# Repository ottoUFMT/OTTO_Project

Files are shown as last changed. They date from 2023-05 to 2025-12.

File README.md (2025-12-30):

# 🤖 Robô Otto - Repositório Oficial

<div align="center">






**Robô educacional interativo com reconhecimento RFID, controle remoto IR, teclado matricial e matriz de LEDs**

[📖 Documentação](#-documentação) • [⚙️ Instalação](#️-instalação) • [🎯 Funcionalidades](#-funcionalidades) • [🚀 Roadmap](#-próximas-funcionalidades)

</div>

---

## 📋 Índice

- [Sobre o Projeto](#-sobre-o-projeto)
- [Características Principais](#-características-principais)
- [Documentação](#-documentação)
- [Pré-requisitos](#-pré-requisitos)
- [Instalação](#️-instalação)
- [Componentes de Hardware](#-componentes-de-hardware)
- [Bibliotecas e Versões](#-bibliotecas-e-versões)
- [Funcionalidades Atuais](#-funcionalidades-atuais)
- [Esquema de Conexões](#-esquema-de-conexões)
- [Como Usar](#-como-usar)
- [Próximas Funcionalidades](#-próximas-funcionalidades)
- [Modelagem 3D](#-modelagem-3d)
- [Troubleshooting](#-troubleshooting)
- [Contribuindo](#-contribuindo)
- [Autores](#-autores)
- [Referências](#-referências)
- [Licença](#-licença)

---

## 🎯 Sobre o Projeto

O **Otto** é um robô educacional open-source desenvolvido para ensinar programação, eletrônica e robótica de forma interativa e divertida. Este repositório contém a versão atual do código, completamente refatorada e documentada, além dos arquivos de modelagem 3D para impressão.

### ✨ Características Principais

- 🎵 **Sistema de Áudio**: Reprodução de músicas e efeitos sonoros via DFPlayer Mini
- 😊 **Expressões Faciais**: Matriz LED 8x8 com 10+ emoções diferentes
- 🎮 **Controle Remoto**: Interface via controle infravermelho
- 💳 **Leitor RFID**: Reconhecimento de cartões para comandos personalizados
- ⌨️ **Teclado Matricial**: 10 teclas para interação direta
- 🕺 **Movimentos**: 4 servos para braços e pernas com coreografias
- 🧠 **Sistema Inteligente**: Respostas emocionais e comportamentos interativos

---

## 📖 Documentação

### 📂 Estrutura do Projeto

```
OTTO_v1_v2/
├──Hardware
│  ├── Bateria.png                #Esquematico da Bateria 
│  ├── Componentes.png            #Esquematico dos Componentes 
│  └── Hardware_2025.pdf          #Esquematicos com melhor resolução 
├──Modelagem_3d
│   ├── amarelo                   #Arquivos para impressão 3D
│   ├── azul                      #Arquivos para impressão 3D
│   └── preto                     #Arquivos para impressão 3D
├──Software
│  └── Programacao_2025.ino       #Código
├──old_versions                   #Arquivos pré 2025
└── README.md                     #Este arquivo
```

### 🔧 Linguagem e Plataforma

- **Linguagem**: C++ (Arduino Framework)
- **Plataforma**: Arduino Mega 2560
- **IDE**: Arduino IDE 1.8.19 ou superior
- **Compilador**: AVR-GCC

---

## 💻 Pré-requisitos

Antes de começar, certifique-se de ter:

### Software

- ✅ **[Visual Studio](https://visualstudio.microsoft.com/pt-br/#vs-section)** - Redistributable C++ (necessário para Arduino IDE)
- ✅ **[Java JRE](https://www.java.com/pt-BR/download/ie_manual.jsp?locale=pt_BR)** 8 ou superior - Runtime para Arduino IDE
- ✅ **[Arduino IDE](https://www.arduino.cc/en/software)** 1.8.19 - Ambiente de desenvolvimento

### Hardware Necessário

| Componente | Quantidade | Especificação |
|---|---|---|
| Arduino Mega 2560 pro mini | 1x | Microcontrolador principal |
| Servo Motor SG90 | 4x | Movimentação de braços e pernas |
| DFPlayer Mini | 1x | Módulo de áudio MP3 |
| Alto-falante | 1x | 3W, 8Ω |
| MFRC522 | 1x | Leitor RFID 13.56MHz |
| Matriz LED 8x8 | 1x | MAX7219 |
| Receptor IR | 1x | VS1838B ou similar |
| Teclado Matricial | 1x | 2x5 (10 teclas) |
| Regulador de Tensão | 1x | LM2596 ou similar (5V, 3A) |
| Bateria | 1x | 7.4V LiPo 2S ou 6x AA |
| Resistores | Diversos | 1kΩ, 10kΩ |

---

## ⚙️ Instalação

### 1️⃣ Preparar o Ambiente

```bash
# 1. Instale Visual Studio Redistributable C++
# Baixe em: https://visualstudio.microsoft.com/pt-br/downloads/

# 2. Instale Java JRE
# Baixe em: https://www.java.com/pt-BR/download/

# 3. Instale Arduino IDE 1.8.19
# Baixe em: https://www.arduino.cc/en/software/OldSoftwareReleases
```

### 2️⃣ Instalar Bibliotecas

Abra o Arduino IDE e instale as bibliotecas via **Sketch → Include Library → Manage Libraries**:

| Biblioteca | Versão | Instalação |
|---|---|---|
| **DFRobotDFPlayerMini** | 1.0.5 | Gerenciador de Bibliotecas |
| **LedControl** | 1.0.6 | Gerenciador de Bibliotecas |
| **MFRC522** | 1.4.10 | Gerenciador de Bibliotecas |
| **IRremote** | 4.0.0+ | [GitHub](https://github.com/Arduino-IRremote/Arduino-IRremote) |
| **Keypad** | 3.1.1 | Gerenciador de Bibliotecas |

**Bibliotecas Nativas** (já incluídas no Arduino):
- `Servo.h`
- `SPI.h`
- `SoftwareSerial.h`
- `avr/wdt.h`

### 3️⃣ Preparar Cartão SD

1. Formate o cartão SD em **FAT32**
2. Crie uma pasta chamada `mp3` na raiz
3. Adicione arquivos de áudio nomeados como:
   - `0001.mp3` - Som de ligar
   - `0002.mp3` - Som de desligar
   - `0084.mp3` - Emoção: Triste
   - `0085.mp3` - Emoção: Feliz
   - (Continue conforme a tabela de áudios)

### 4️⃣ Upload do Código

```bash
# 1. Conecte o Arduino Mega via USB
# 2. Selecione a placa: Tools → Board → Arduino Mega 2560
# 3. Selecione a porta: Tools → Port → COMx (Windows) ou /dev/ttyUSBx (Linux)
# 4. Clique em Upload (→)
```

---

## 🔌 Componentes de Hardware

### Pinagem Detalhada

#### **Servos Motores**
```cpp
Pino 2  → Perna Esquerda (Left Foot)
Pino 3  → Perna Direita (Right Foot)
Pino 6  → Braço Esquerdo (Left Arm)
Pino 7  → Braço Direito (Right Arm)
```

#### **DFPlayer Mini (Áudio)**
```cpp
Pino 11 → RX (DFPlayer)
Pino 10 → TX (DFPlayer)
        → VCC → 5V (regulado)
        → GND → GND
        → SPK+ → Alto-falante +
        → SPK- → Alto-falante -
```

#### **MFRC522 (RFID)**
```cpp
Pino 5  → RST
Pino 53 → SDA/SS
Pino 51 → MOSI
Pino 50 → MISO
Pino 52 → SCK
        → 3.3V → 3.3V
        → GND → GND
```

#### **Matriz LED 8x8 (MAX7219)**
```cpp
Pino 22 → DIN (Data In)
Pino 24 → CLK (Clock)
Pino 26 → CS (Chip Select)
        → VCC → 5V
        → GND → GND
```

#### **Receptor IR**
```cpp
Pino 13 → Signal
        → VCC → 5V
        → GND → GND
```

#### **Teclado Matricial 2x5**
```cpp
Linhas:  Pino 40, 38
Colunas: Pino 42, 44, 46, 48, 47
```

---

## 📚 Bibliotecas e Versões

| Biblioteca | Versão | Descrição | Download |
|---|---|---|---|
| **Arduino IDE** | 1.8.19 / 1.8.57.0 | Ambiente de desenvolvimento | [Link](https://www.arduino.cc/en/software/OldSoftwareReleases) |
| **DFRobotDFPlayerMini** | 1.0.5 | Controle do módulo MP3 | [GitHub](https://github.com/DFRobot/DFRobotDFPlayerMini) |
| **LedControl** | 1.0.6 | Controle de matriz LED MAX7219 | [Arduino Lib](https://github.com/wayoda/LedControl) |
| **MFRC522** | 1.4.10 | Biblioteca para leitor RFID | [GitHub](https://github.com/miguelbalboa/rfid) |
| **IRremote** | 4.0.0+ | Recepção de sinais infravermelhos | [GitHub](https://github.com/Arduino-IRremote/Arduino-IRremote) |
| **Keypad** | 3.1.1 | Leitura de teclado matricial | [Playground](https://playground.arduino.cc/Code/Keypad/) |
| **Servo** | Nativa | Controle de servos motores | Incluída no Arduino |
| **SPI** | Nativa | Comunicação SPI | Incluída no Arduino |
| **SoftwareSerial** | Nativa | Serial por software | Incluída no Arduino |
| **avr/wdt** | Nativa | Watchdog Timer | Incluída no Arduino |

---

## 🎯 Funcionalidades Atuais

### 🎵 Sistema de Áudio
- ✅ Reprodução de 100+ arquivos MP3
- ✅ Controle de volume (0-30)
- ✅ Sons de emoções sincronizados
- ✅ Efeitos sonoros para movimentos

### 😊 Expressões Faciais (LED Matrix)
| Emoção | Código | Descrição |
|---|---|---|
| 😊 Feliz | 85 | Sorriso + comemoração |
| 😢 Triste | 84 | Face triste + braços caídos |
| 😠 Raiva | 89 | Face brava + braços tremendo |
| 😨 Medo | 87 | Face assustada |
| 😳 Vergonha | 86 | Face tímida |
| 🤢 Enjoado | 91 | Face nauseada |
| 😴 Cansado | 108 | Face sonolenta |
| 😲 Surpreso | 90 | Face de susto |
| ❤️ Amor | 95 | Coração nos olhos |
| 😐 Neutro | - | Face padrão |

### 🎮 Controle Remoto IR
| Botão | Código | Função |
|---|---|---|
| POWER | 0xBA45FF00 | Liga/Desliga robô |
| 1 | 0xF30CFF00 | Resposta positiva (acertou) |
| 3 | 0xA15EFF00 | Resposta negativa (errou) |
| 5 | 0xE31CFF00 | Modo dança |
| VERDE | 0xB847FF00 | Liga/Desliga teclado |

### 💳 Cartões RFID
- Emoções: Cartões 84-91, 106-108
- Músicas: Qualquer outro número
- Comandos especiais: Parabéns (107)

### ⌨️ Teclado Matricial
- Teclas 0-9 tocam áudios 97-106
- Habilitação via controle remoto
- Feedback sonoro imediato

### 🕺 Movimentos
- **Acenar**: Cumprimento com braço direito
- **Comemorar**: Braços para cima e baixo (4 ciclos)
- **Tristeza**: Braços caem desanimados
- **Raiva**: Braços tremendo rapidamente
- **Dança**: Coreografia completa (pernas + braços)

---

## 🔗 Esquema de Conexões

### Diagrama de Componentes
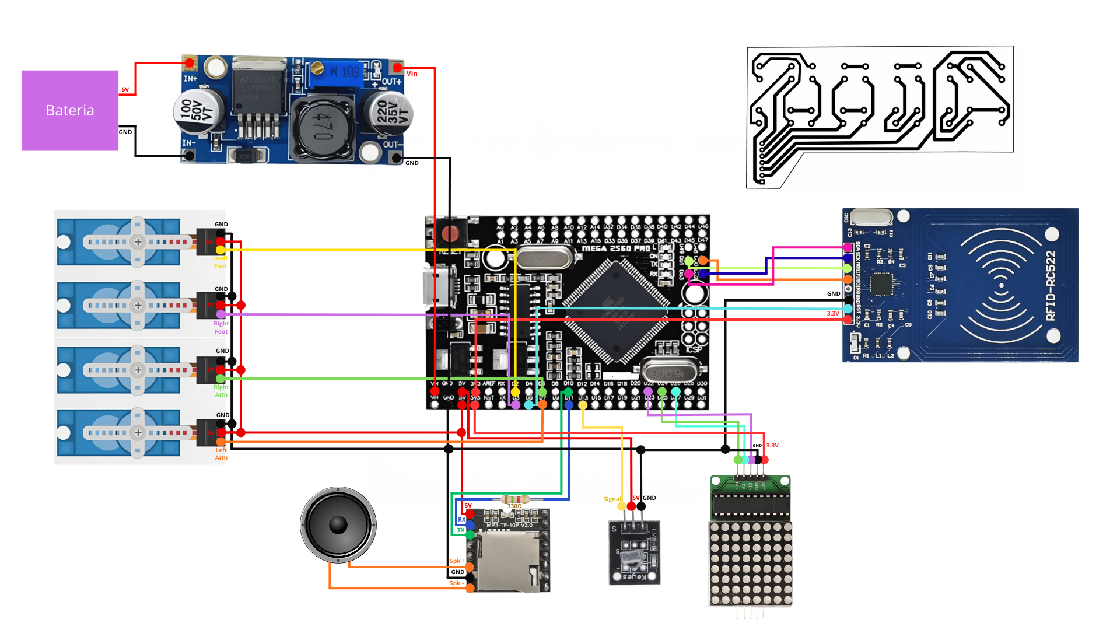
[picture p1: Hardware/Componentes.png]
Componentes


### Circuito Elétrico do Sistema de Alimentação do Otto
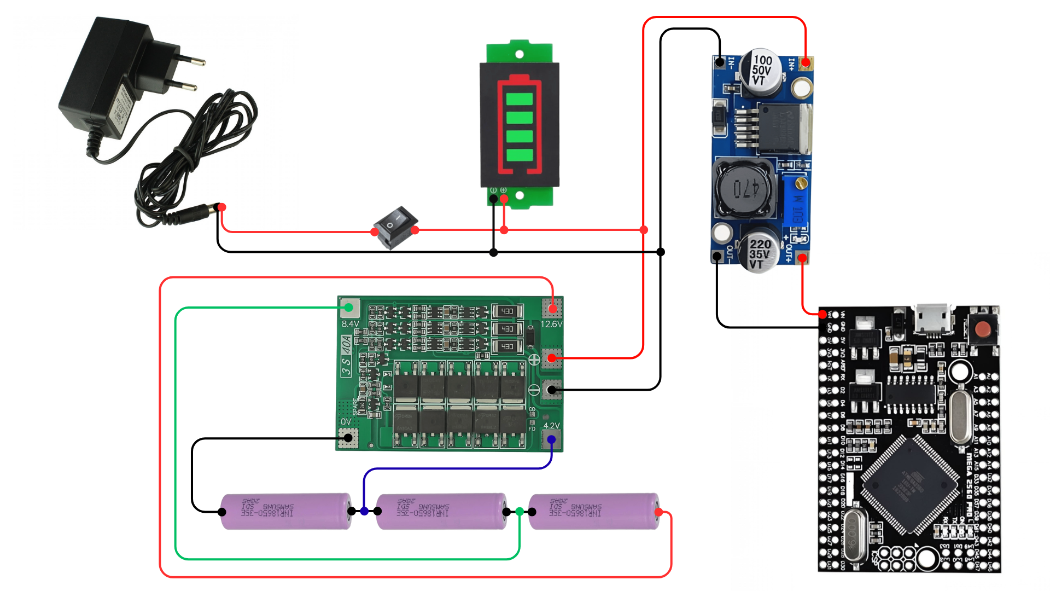
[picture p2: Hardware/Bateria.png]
Bateria


Para saber as [especificações técnicas da bateria](https://github.com/ottoUFMT/OTTO_v1_v2/blob/9e59030a3d1729480948bee1795932de72b58ab2/Bateria/Especifica%C3%A7%C3%B5es.txt), basta acessar a pasta correspondente, lá consta o seu [datasheet](https://github.com/ottoUFMT/OTTO_v1_v2/blob/9e59030a3d1729480948bee1795932de72b58ab2/Bateria/BMS-40A-3S_DATASHEET.pdf), sobre o [mostrador de bateria](https://github.com/ottoUFMT/OTTO_v1_v2/blob/9e59030a3d1729480948bee1795932de72b58ab2/Bateria/Mostrador%20de%20bateria.png), bem como ligações elétricas.

### Componentes Principais
```
┌─────────────────────────────────────────┐
│         Arduino Mega 2560 pro           │
│                                         │
│  [Servos] [DFPlayer] [RFID] [IR] [LED]  │
│     │         │         │      │     │  │
└─────┼─────────┼─────────┼──────┼─────┼──┘
      │         │         │      │     │
    Braços   Alto-    Cartões  Controle LEDs
    Pernas   Falante           Remoto   Matriz
```

---

## 🚀 Como Usar

### Inicialização

1. **Ligue o robô**: Pressione o botão POWER do controle
2. **Aguarde**: Otto mostra coração ❤️ e acena 👋
3. **Pronto**: Face neutra indica que está pronto

### Interações Básicas

#### Via Controle Remoto
```
POWER → Liga/Desliga
  1   → Elogio (acertou) → Otto comemora 🎉
  3   → Feedback negativo (errou) → Otto fica triste 😢
  5   → Inicia dança 🕺
VERDE → Habilita/desabilita teclado
```

#### Via Teclado Matricial
```
1. Pressione VERDE no controle para habilitar
2. Pressione qualquer tecla (0-9)
3. Otto reproduz áudio correspondente
```

#### Via Cartões RFID
```
1. Aproxime cartão do leitor
2. Otto identifica o número gravado
3. Executa ação correspondente:
   - Emoções (84-91): Som + expressão + movimento
   - Músicas (outros): Som + animação de fala
```

### Desligamento
```
1. Pressione POWER no controle
2. Otto acena tchau 👋
3. Toca som de despedida
4. Display apaga e sistema desliga
```

---

## 🚀 Próximas Funcionalidades

### 📋 Roadmap v3.0

#### 🔧 Hardware
- [ ] **Teclado Touch Capacitivo**: Substituir teclado mecânico por touch
- [ ] **Orelhas Móveis**: Adicionar servos para movimento de orelhas
- [ ] **Corpo Articulado**: Movimento de torção do corpo
- [ ] **Olhos RGB**: LEDs coloridos nos olhos com efeitos
- [ ] **Cabos Blindados**: Substituir jumpers por cabos blindados para reduzir interferência
- [ ] **PCB Personalizada**: Board com conectores parafusados para regulador de tensão
- [ ] **Proteção Elétrica**: Fusível de proteção para bateria

#### 🎨 Melhorias
- [ ] **Mais Emoções**: Expandir biblioteca de expressões
- [ ] **Coreografias**: Novas danças e movimentos
- [ ] **Jogos Interativos**: Mini-games educativos

---

## 🎨 Modelagem 3D

### 📐 Arquivos para Impressão

Todos os arquivos STL estão na pasta `Hardware/`

### Requisitos de Impressão

| Especificação | Valor |
|---|---|
| **Impressora** | Mesa mínima 25x25cm |
| **Resolução** | 0.2mm (camada) |
| **Preenchimento** | 20-30% |
| **Suporte** | Necessário em algumas peças |
| **Material** | PLA ou PETG |
| **Temperatura Bico** | 200-210°C (PLA) |
| **Temperatura Mesa** | 60°C |

### Software Recomendado

- **Modelagem**: [Autodesk Fusion 360](https://www.autodesk.com/products/fusion-360/)
- **Fatiamento**: [Ultimaker Cura](https://ultimaker.com/software/ultimaker-cura) 3.0+
- **Visualização**: Qualquer visualizador STL

### Peças para Imprimir

```
📦 otto_1.0-stl/
├── 🦴 corpo.stl           (1x) - 4-5 horas
├── 🦿 perna_esquerda.stl  (1x) - 2 horas
├── 🦿 perna_direita.stl   (1x) - 2 horas
├── 💪 braco_esquerdo.stl  (1x) - 1 hora
├── 💪 braco_direito.stl   (1x) - 1 hora
├── 🤖 cabeca_frente.stl   (1x) - 3 horas
└── 🤖 cabeca_tras.stl     (1x) - 2 horas

⏱️ Tempo total estimado: 15-20 horas
```

---

## 🐛 Troubleshooting

### Problemas Comuns

#### 1. DFPlayer não inicializa
```
Erro: "Nao inicializado: Cheque as conexoes"

Soluções:
✅ Verifique conexões TX/RX (pinos 11 e 10)
✅ Use resistor de 1kΩ no RX do DFPlayer
✅ Formate cartão SD em FAT32
✅ Renomeie arquivos: 0001.mp3, 0002.mp3...
✅ Teste cartão em outro dispositivo
```

#### 2. RFID não lê cartões
```
Erro: Cartão não é detectado

Soluções:
✅ Verifique alimentação 3.3V (não use 5V!)
✅ Confirme conexões SPI (MOSI, MISO, SCK)
✅ Aproxime cartão a menos de 3cm
✅ Teste com diferentes cartões
✅ Verifique se biblioteca MFRC522 está instalada
```

#### 3. Servos tremem ou não respondem
```
Problema: Movimento irregular

Soluções:
✅ Use fonte externa de 5V, 3A mínimo
✅ Adicione capacitor de 1000µF na alimentação
✅ Verifique se fios não estão soltos
✅ Calibre posição inicial dos servos (90°)
✅ Reduza carga (remova peso extra)
```

#### 4. IR não responde
```
Problema: Controle remoto não funciona

Soluções:
✅ Troque baterias do controle
✅ Aponte diretamente para o receptor
✅ Verifique pino 30 do receptor IR
✅ Teste com Serial Monitor para ver códigos
✅ Troque receptor se necessário
```

#### 5. Matriz LED não acende
```
Problema: Display não mostra nada

Soluções:
✅ Verifique pinos DIN (22), CLK (24), CS (26)
✅ Confirme alimentação 5V estável
✅ Teste com código de exemplo do LedControl
✅ Verifique orientação do módulo MAX7219
```

---

## 🤝 Contribuindo

Contribuições são sempre bem-vindas! Siga os passos:

### Como Contribuir

1. **Fork** o projeto
2. **Clone** seu fork
   ```bash
   git clone https://github.com/seu-usuario/OTTO_v1_v2.git
   ```
3. Crie uma **branch** para sua feature
   ```bash
   git checkout -b feature/MinhaFeature
   ```
4. **Commit** suas mudanças
   ```bash
   git commit -m "Adiciona: Minha nova feature"
   ```
5. **Push** para a branch
   ```bash
   git push origin feature/MinhaFeature
   ```
6. Abra um **Pull Request**

### Diretrizes

- 📝 Comente seu código adequadamente
- ✅ Teste antes de enviar
- 📚 Atualize documentação se necessário
- 🎯 Mantenha código limpo e organizado
- 🐛 Reporte bugs com detalhes

---

## 👥 Autores

### 💻 Desenvolvimento de Software

<table>
  <tr>
    <td align="center">
      <a href="https://github.com/defaultdayanni">
        Foto Dayanni<br>
        <sub>
          <b>Dayanni</b><br>
          <small>Programação & Eletrônica</small>
        </sub>
      </a>
    </td>
    <td align="center">
      <a href="https://github.com/DebbieMatt">
        Foto da Débora<br>
        <sub>
          <b>Débora Mateus</b><br>
          <small>Programação & Eletrônica</small>
        </sub>
      </a>
    </td>
    <td align="center">
      <a href="https://github.com/luizgsantos-dev">
        Sua Foto do Luiz<br>
        <sub>
          <b>Luiz Guilherme</b><br>
          <small>Programação & Eletrônica</small>
        </sub>
      </a>
    </td>
  </tr>
</table>

### 🎨 Modelagem 3D

<table>
  <tr>
    <td align="center">
      <a href="https://github.com/gabereboucas">
        Foto do Gabriel Rebouças<br>
        <sub>
          <b>Gabriel Rebouças</b><br>
          <small>Modelagem & Impressão 3D</small>
        </sub>
      </a>
    </td>
  </tr>
</table>

---

## 📚 Referências

### Documentação Oficial

- [Arduino - Referência Oficial](https://www.arduino.cc/reference/en/)
- [Arduino IDE - Download](https://www.arduino.cc/en/software)
- [Arduino - Versões Anteriores](https://www.arduino.cc/en/software/OldSoftwareReleases)

### Bibliotecas

- [DFPlayer Mini - DFRobot](https://github.com/DFRobot/DFRobotDFPlayerMini)
- [MFRC522 - RFID Library](https://github.com/miguelbalboa/rfid)
- [IRremote - Arduino](https://github.com/Arduino-IRremote/Arduino-IRremote)
- [Keypad - Arduino Playground](https://playground.arduino.cc/Code/Keypad/)
- [LedControl - Wayoda](https://github.com/wayoda/LedControl)

### Ferramentas

- [Visual Studio C++](https://visualstudio.microsoft.com/pt-br/)
- [Java Runtime Environment](https://www.java.com/pt-BR/download/)
- [Autodesk Fusion 360](https://www.autodesk.com/products/fusion-360/)
- [Ultimaker Cura](https://ultimaker.com/software/ultimaker-cura)

### Projetos Relacionados

- [Otto DIY - Projeto Original](https://www.ottodiy.com/)
- [Arduino Servo Library](https://www.arduino.cc/reference/en/libraries/servo/)
- [SPI Communication](https://www.arduino.cc/en/reference/SPI)

---

## 📄 Licença

Este projeto está sob a licença MIT. Veja o arquivo [LICENSE](LICENSE) para mais detalhes.

```
MIT License

Copyright (c) 2024 Otto UFMT

Permission is hereby granted, free of charge, to any person obtaining a copy
of this software and associated documentation files (the "Software"), to deal
in the Software without restriction, including without limitation the rights
to use, copy, modify, merge, publish, distribute, sublicense, and/or sell
copies of the Software...
```

---

### 💙 Se este projeto foi útil, considere dar uma ⭐!

**[⬆ Voltar ao topo](#-robô-otto-10---repositório-oficial)**

---

**Desenvolvido com ❤️ pela equipe Otto UFMT**



</div>

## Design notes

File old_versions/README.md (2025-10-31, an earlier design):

# 🤖 Robô Otto 1.0 - Repositório Oficial

<div align="center">






**Robô educacional interativo com reconhecimento RFID, controle remoto IR, teclado matricial e matriz de LEDs**

[📖 Documentação](#-documentação) • [⚙️ Instalação](#️-instalação) • [🎯 Funcionalidades](#-funcionalidades) • [🚀 Roadmap](#-próximas-funcionalidades)

</div>

---

## 📋 Índice

- [Sobre o Projeto](#-sobre-o-projeto)
- [Características Principais](#-características-principais)
- [Documentação](#-documentação)
- [Pré-requisitos](#-pré-requisitos)
- [Instalação](#️-instalação)
- [Componentes de Hardware](#-componentes-de-hardware)
- [Bibliotecas e Versões](#-bibliotecas-e-versões)
- [Funcionalidades Atuais](#-funcionalidades-atuais)
- [Esquema de Conexões](#-esquema-de-conexões)
- [Como Usar](#-como-usar)
- [Próximas Funcionalidades](#-próximas-funcionalidades)
- [Modelagem 3D](#-modelagem-3d)
- [Troubleshooting](#-troubleshooting)
- [Contribuindo](#-contribuindo)
- [Autores](#-autores)
- [Referências](#-referências)
- [Licença](#-licença)

---

## 🎯 Sobre o Projeto

O **Otto 1.0** é um robô educacional open-source desenvolvido para ensinar programação, eletrônica e robótica de forma interativa e divertida. Este repositório contém a versão 2.0 do código, completamente refatorada e documentada, além dos arquivos de modelagem 3D para impressão.

### ✨ Características Principais

- 🎵 **Sistema de Áudio**: Reprodução de músicas e efeitos sonoros via DFPlayer Mini
- 😊 **Expressões Faciais**: Matriz LED 8x8 com 10+ emoções diferentes
- 🎮 **Controle Remoto**: Interface via controle infravermelho
- 💳 **Leitor RFID**: Reconhecimento de cartões para comandos personalizados
- ⌨️ **Teclado Matricial**: 10 teclas para interação direta
- 🕺 **Movimentos**: 4 servos para braços e pernas com coreografias
- 🧠 **Sistema Inteligente**: Respostas emocionais e comportamentos interativos

---

## 📖 Documentação

### 📂 Estrutura do Projeto

```
OTTO_v1_v2/
├── Prog_otto_03_10_oficial.ino    # Código principal (versão original)
├── Otto_Improved.ino               # Código refatorado v2.0
├── otto_1.0-stl/                   # Arquivos para impressão 3D
│   ├── corpo.stl
│   ├── pernas.stl
│   ├── bracos.stl
│   └── cabeca.stl
├── Esquemático Circuito.jpeg       # Diagrama de conexões
├── Reprodutor de MP3.jpeg          # Ilustração do sistema de áudio
└── README.md                       # Este arquivo
```

### 🔧 Linguagem e Plataforma

- **Linguagem**: C++ (Arduino Framework)
- **Plataforma**: Arduino Mega 2560
- **IDE**: Arduino IDE 1.8.19 ou superior
- **Compilador**: AVR-GCC

---

## 💻 Pré-requisitos

Antes de começar, certifique-se de ter:

### Software

- ✅ **[Visual Studio](https://visualstudio.microsoft.com/pt-br/#vs-section)** - Redistributable C++ (necessário para Arduino IDE)
- ✅ **[Java JRE](https://www.java.com/pt-BR/download/ie_manual.jsp?locale=pt_BR)** 8 ou superior - Runtime para Arduino IDE
- ✅ **[Arduino IDE](https://www.arduino.cc/en/software)** 1.8.19 - Ambiente de desenvolvimento

### Hardware Necessário

| Componente | Quantidade | Especificação |
|---|---|---|
| Arduino Mega 2560 | 1x | Microcontrolador principal |
| Servo Motor SG90 | 4x | Movimentação de braços e pernas |
| DFPlayer Mini | 1x | Módulo de áudio MP3 |
| Alto-falante | 1x | 3W, 8Ω |
| MFRC522 | 1x | Leitor RFID 13.56MHz |
| Matriz LED 8x8 | 1x | MAX7219 |
| Receptor IR | 1x | VS1838B ou similar |
| Teclado Matricial | 1x | 2x5 (10 teclas) |
| Regulador de Tensão | 1x | LM2596 ou similar (5V, 3A) |
| Capacitor | 1x | 1000µF, 16V (estabilização) |
| Bateria | 1x | 7.4V LiPo 2S ou 6x AA |
| Resistores | Diversos | 1kΩ, 10kΩ |

---

## ⚙️ Instalação

### 1️⃣ Preparar o Ambiente

```bash
# 1. Instale Visual Studio Redistributable C++
# Baixe em: https://visualstudio.microsoft.com/pt-br/downloads/

# 2. Instale Java JRE
# Baixe em: https://www.java.com/pt-BR/download/

# 3. Instale Arduino IDE 1.8.19
# Baixe em: https://www.arduino.cc/en/software/OldSoftwareReleases
```

### 2️⃣ Instalar Bibliotecas

Abra o Arduino IDE e instale as bibliotecas via **Sketch → Include Library → Manage Libraries**:

| Biblioteca | Versão | Instalação |
|---|---|---|
| **DFRobotDFPlayerMini** | 1.0.5 | Gerenciador de Bibliotecas |
| **LedControl** | 1.0.6 | Gerenciador de Bibliotecas |
| **MFRC522** | 1.4.10 | Gerenciador de Bibliotecas |
| **IRremote** | 4.0.0+ | [GitHub](https://github.com/Arduino-IRremote/Arduino-IRremote) |
| **Keypad** | 3.1.1 | Gerenciador de Bibliotecas |

**Bibliotecas Nativas** (já incluídas no Arduino):
- `Servo.h`
- `SPI.h`
- `SoftwareSerial.h`
- `avr/wdt.h`

### 3️⃣ Preparar Cartão SD

1. Formate o cartão SD em **FAT32**
2. Crie uma pasta chamada `mp3` na raiz
3. Adicione arquivos de áudio nomeados como:
   - `0001.mp3` - Som de ligar
   - `0002.mp3` - Som de desligar
   - `0084.mp3` - Emoção: Triste
   - `0085.mp3` - Emoção: Feliz
   - (Continue conforme a tabela de áudios)

### 4️⃣ Upload do Código

```bash
# 1. Conecte o Arduino Mega via USB
# 2. Selecione a placa: Tools → Board → Arduino Mega 2560
# 3. Selecione a porta: Tools → Port → COMx (Windows) ou /dev/ttyUSBx (Linux)
# 4. Clique em Upload (→)
```

---

## 🔌 Componentes de Hardware

### Pinagem Detalhada

#### **Servos Motores**
```cpp
Pino 2  → Perna Esquerda (Left Foot)
Pino 3  → Perna Direita (Right Foot)
Pino 6  → Braço Esquerdo (Left Arm)
Pino 7  → Braço Direito (Right Arm)
```

#### **DFPlayer Mini (Áudio)**
```cpp
Pino 10 → RX (DFPlayer)
Pino 11 → TX (DFPlayer)
        → VCC → 5V (regulado)
        → GND → GND
        → SPK+ → Alto-falante +
        → SPK- → Alto-falante -
```

#### **MFRC522 (RFID)**
```cpp
Pino 5  → RST
Pino 53 → SDA/SS
Pino 51 → MOSI
Pino 50 → MISO
Pino 52 → SCK
        → 3.3V → 3.3V
        → GND → GND
```

#### **Matriz LED 8x8 (MAX7219)**
```cpp
Pino 22 → DIN (Data In)
Pino 24 → CLK (Clock)
Pino 26 → CS (Chip Select)
        → VCC → 5V
        → GND → GND
```

#### **Receptor IR**
```cpp
Pino 30 → Signal
        → VCC → 5V
        → GND → GND
```

#### **Teclado Matricial 2x5**
```cpp
Linhas:  Pino 40, 38
Colunas: Pino 42, 44, 46, 48, 49
```

---

## 📚 Bibliotecas e Versões

| Biblioteca | Versão | Descrição | Download |
|---|---|---|---|
| **Arduino IDE** | 1.8.19 / 1.8.57.0 | Ambiente de desenvolvimento | [Link](https://www.arduino.cc/en/software/OldSoftwareReleases) |
| **DFRobotDFPlayerMini** | 1.0.5 | Controle do módulo MP3 | [GitHub](https://github.com/DFRobot/DFRobotDFPlayerMini) |
| **LedControl** | 1.0.6 | Controle de matriz LED MAX7219 | [Arduino Lib](https://github.com/wayoda/LedControl) |
| **MFRC522** | 1.4.10 | Biblioteca para leitor RFID | [GitHub](https://github.com/miguelbalboa/rfid) |
| **IRremote** | 4.0.0+ | Recepção de sinais infravermelhos | [GitHub](https://github.com/Arduino-IRremote/Arduino-IRremote) |
| **Keypad** | 3.1.1 | Leitura de teclado matricial | [Playground](https://playground.arduino.cc/Code/Keypad/) |
| **Servo** | Nativa | Controle de servos motores | Incluída no Arduino |
| **SPI** | Nativa | Comunicação SPI | Incluída no Arduino |
| **SoftwareSerial** | Nativa | Serial por software | Incluída no Arduino |
| **avr/wdt** | Nativa | Watchdog Timer | Incluída no Arduino |

---

## 🎯 Funcionalidades Atuais

### 🎵 Sistema de Áudio
- ✅ Reprodução de 100+ arquivos MP3
- ✅ Controle de volume (0-30)
- ✅ Sons de emoções sincronizados
- ✅ Efeitos sonoros para movimentos

### 😊 Expressões Faciais (LED Matrix)
| Emoção | Código | Descrição |
|---|---|---|
| 😊 Feliz | 85 | Sorriso + comemoração |
| 😢 Triste | 84 | Face triste + braços caídos |
| 😠 Raiva | 89 | Face brava + braços tremendo |
| 😨 Medo | 87 | Face assustada |
| 😳 Vergonha | 86 | Face tímida |
| 🤢 Enjoado | 91 | Face nauseada |
| 😴 Cansado | 108 | Face sonolenta |
| 😲 Surpreso | 90 | Face de susto |
| ❤️ Amor | 95 | Coração nos olhos |
| 😐 Neutro | - | Face padrão |

### 🎮 Controle Remoto IR
| Botão | Código | Função |
|---|---|---|
| POWER | 0xBA45FF00 | Liga/Desliga robô |
| 1 | 0xF30CFF00 | Resposta positiva (acertou) |
| 3 | 0xA15EFF00 | Resposta negativa (errou) |
| 5 | 0xE31CFF00 | Modo dança |
| VERDE | 0xB847FF00 | Liga/Desliga teclado |

### 💳 Cartões RFID
- Emoções: Cartões 84-91, 106-108
- Músicas: Qualquer outro número
- Comandos especiais: Parabéns (107)

### ⌨️ Teclado Matricial
- Teclas 0-9 tocam áudios 97-106
- Habilitação via controle remoto
- Feedback sonoro imediato

### 🕺 Movimentos
- **Acenar**: Cumprimento com braço direito
- **Comemorar**: Braços para cima e baixo (4 ciclos)
- **Tristeza**: Braços caem desanimados
- **Raiva**: Braços tremendo rapidamente
- **Dança**: Coreografia completa (pernas + braços)

---

## 🔗 Esquema de Conexões

### Diagrama (desconsidere o potenciometro, ele foi retirado, o alto falante é ligado diretamente no DFPlayer)
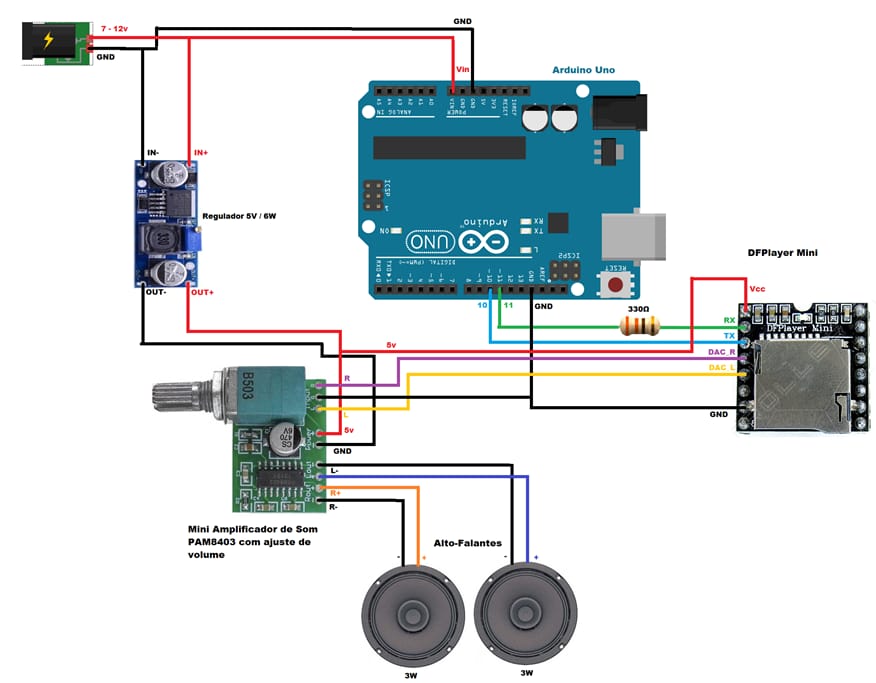
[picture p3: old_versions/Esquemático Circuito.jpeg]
Esquemático do Circuito


### Esquema Eletrico
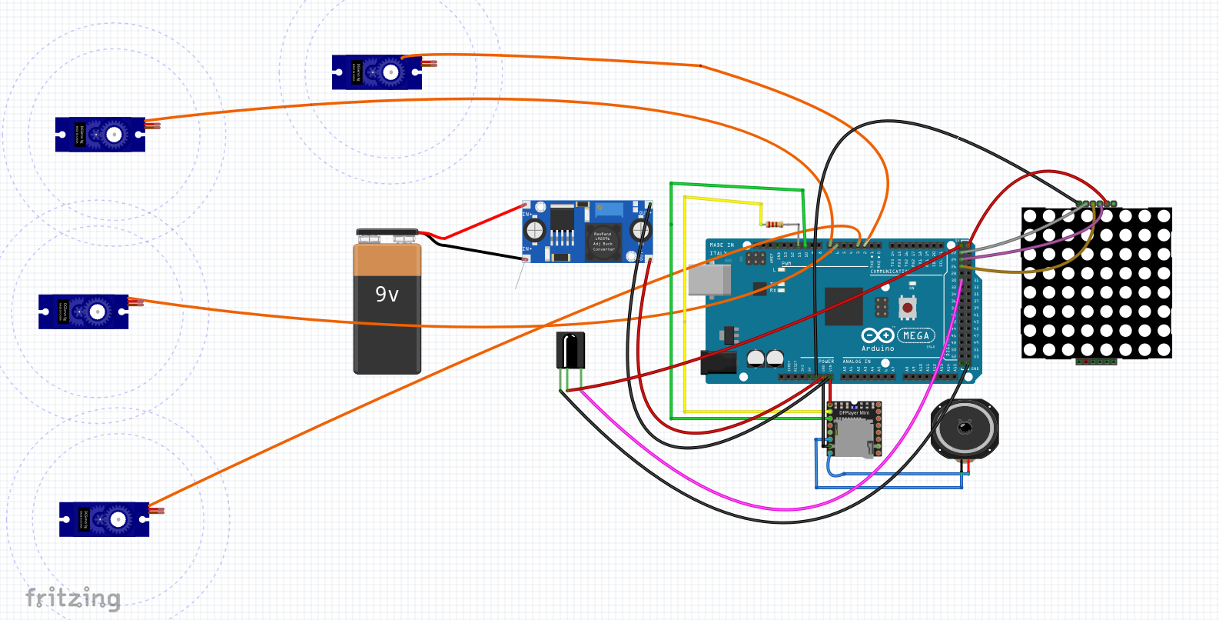
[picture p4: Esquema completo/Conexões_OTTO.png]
Esquema elétrico


### Circuito Elétrico do Sistema de Alimentação do Otto

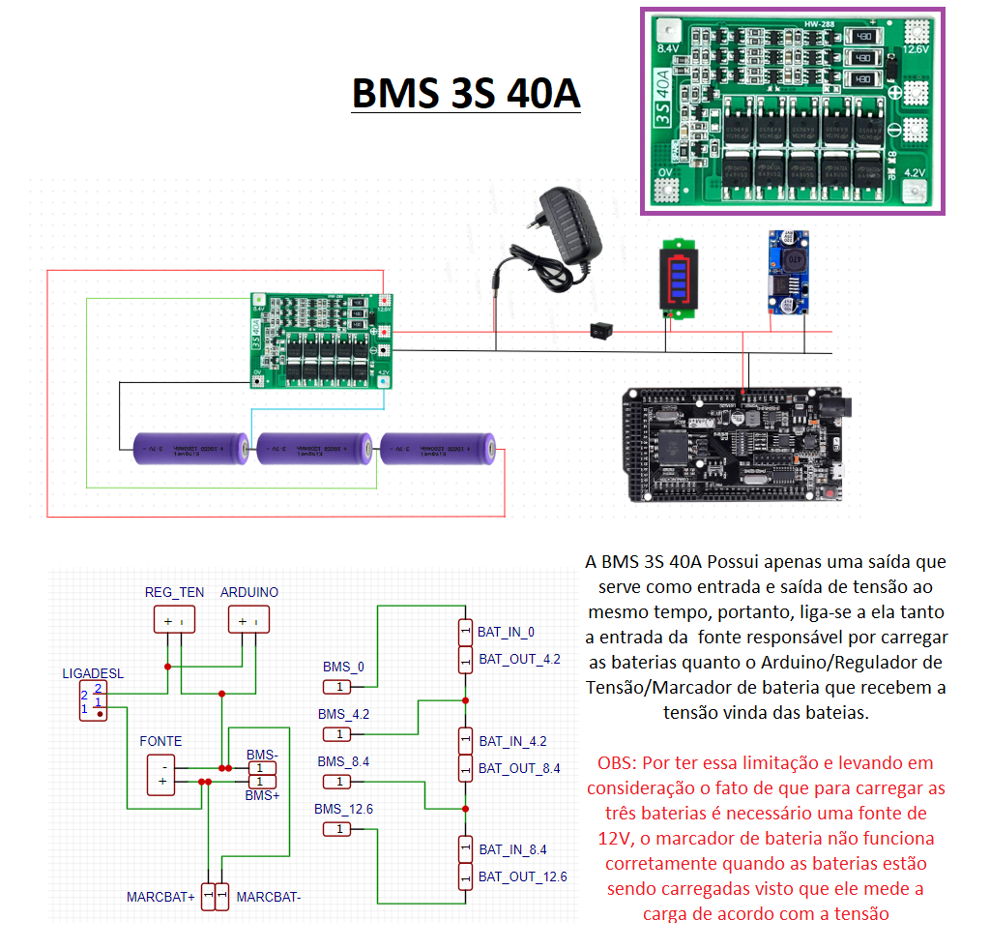
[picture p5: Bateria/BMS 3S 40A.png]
BateriaBMS2040A


Para saber as [especificações técnicas da bateria](https://github.com/ottoUFMT/OTTO_v1_v2/blob/9e59030a3d1729480948bee1795932de72b58ab2/Bateria/Especifica%C3%A7%C3%B5es.txt), basta acessar a pasta correspondente, lá consta o seu [datasheet](https://github.com/ottoUFMT/OTTO_v1_v2/blob/9e59030a3d1729480948bee1795932de72b58ab2/Bateria/BMS-40A-3S_DATASHEET.pdf), sobre o [mostrador de bateria](https://github.com/ottoUFMT/OTTO_v1_v2/blob/9e59030a3d1729480948bee1795932de72b58ab2/Bateria/Mostrador%20de%20bateria.png), bem como ligações elétricas.

### Componentes Principais
```
┌─────────────────────────────────────────┐
│         Arduino Mega 2560               │
│                                         │
│  [Servos] [DFPlayer] [RFID] [IR] [LED] │
│     │         │         │      │     │  │
└─────┼─────────┼─────────┼──────┼─────┼──┘
      │         │         │      │     │
    Braços   Alto-    Cartões  Controle LEDs
    Pernas   Falante           Remoto   Matriz
```

---

## 🚀 Como Usar

### Inicialização

1. **Ligue o robô**: Pressione o botão POWER do controle
2. **Aguarde**: Otto mostra coração ❤️ e acena 👋
3. **Pronto**: Face neutra indica que está pronto

### Interações Básicas

#### Via Controle Remoto
```
POWER → Liga/Desliga
  1   → Elogio (acertou) → Otto comemora 🎉
  3   → Feedback negativo (errou) → Otto fica triste 😢
  5   → Inicia dança 🕺
VERDE → Habilita/desabilita teclado
```

#### Via Teclado Matricial
```
1. Pressione VERDE no controle para habilitar
2. Pressione qualquer tecla (0-9)
3. Otto reproduz áudio correspondente
```

#### Via Cartões RFID
```
1. Aproxime cartão do leitor
2. Otto identifica o número gravado
3. Executa ação correspondente:
   - Emoções (84-91): Som + expressão + movimento
   - Músicas (outros): Som + animação de fala
```

### Desligamento
```
1. Pressione POWER no controle
2. Otto acena tchau 👋
3. Toca som de despedida
4. Display apaga e sistema desliga
```

---

## 🚀 Próximas Funcionalidades

### 📋 Roadmap v3.0

#### 🔧 Hardware
- [ ] **Teclado Touch Capacitivo**: Substituir teclado mecânico por touch
- [ ] **Orelhas Móveis**: Adicionar servos para movimento de orelhas
- [ ] **Corpo Articulado**: Movimento de torção do corpo
- [ ] **Olhos RGB**: LEDs coloridos nos olhos com efeitos
- [ ] **Cabos Blindados**: Substituir jumpers por cabos blindados para reduzir interferência
- [ ] **PCB Personalizada**: Board com conectores parafusados para regulador de tensão
- [ ] **Proteção Elétrica**: Fusível de proteção para bateria

#### 🎨 Melhorias
- [ ] **Mais Emoções**: Expandir biblioteca de expressões
- [ ] **Coreografias**: Novas danças e movimentos
- [ ] **Jogos Interativos**: Mini-games educativos

---

## 🎨 Modelagem 3D

### 📐 Arquivos para Impressão

Todos os arquivos STL estão na pasta `otto_1.0-stl/`

### Requisitos de Impressão

| Especificação | Valor |
|---|---|
| **Impressora** | Mesa mínima 25x25cm |
| **Resolução** | 0.2mm (camada) |
| **Preenchimento** | 20-30% |
| **Suporte** | Necessário em algumas peças |
| **Material** | PLA ou PETG |
| **Temperatura Bico** | 200-210°C (PLA) |
| **Temperatura Mesa** | 60°C |

### Software Recomendado

- **Modelagem**: [Autodesk Fusion 360](https://www.autodesk.com/products/fusion-360/)
- **Fatiamento**: [Ultimaker Cura](https://ultimaker.com/software/ultimaker-cura) 3.0+
- **Visualização**: Qualquer visualizador STL

### Peças para Imprimir

```
📦 otto_1.0-stl/
├── 🦴 corpo.stl           (1x) - 4-5 horas
├── 🦿 perna_esquerda.stl  (1x) - 2 horas
├── 🦿 perna_direita.stl   (1x) - 2 horas
├── 💪 braco_esquerdo.stl  (1x) - 1 hora
├── 💪 braco_direito.stl   (1x) - 1 hora
├── 🤖 cabeca_frente.stl   (1x) - 3 horas
└── 🤖 cabeca_tras.stl     (1x) - 2 horas

⏱️ Tempo total estimado: 15-20 horas
```

---

## 🐛 Troubleshooting

### Problemas Comuns

#### 1. DFPlayer não inicializa
```
Erro: "Nao inicializado: Cheque as conexoes"

Soluções:
✅ Verifique conexões TX/RX (pinos 10 e 11)
✅ Use resistor de 1kΩ no RX do DFPlayer
✅ Formate cartão SD em FAT32
✅ Renomeie arquivos: 0001.mp3, 0002.mp3...
✅ Teste cartão em outro dispositivo
```

#### 2. RFID não lê cartões
```
Erro: Cartão não é detectado

Soluções:
✅ Verifique alimentação 3.3V (não use 5V!)
✅ Confirme conexões SPI (MOSI, MISO, SCK)
✅ Aproxime cartão a menos de 3cm
✅ Teste com diferentes cartões
✅ Verifique se biblioteca MFRC522 está instalada
```

#### 3. Servos tremem ou não respondem
```
Problema: Movimento irregular

Soluções:
✅ Use fonte externa de 5V, 3A mínimo
✅ Adicione capacitor de 1000µF na alimentação
✅ Verifique se fios não estão soltos
✅ Calibre posição inicial dos servos (90°)
✅ Reduza carga (remova peso extra)
```

#### 4. IR não responde
```
Problema: Controle remoto não funciona

Soluções:
✅ Troque baterias do controle
✅ Aponte diretamente para o receptor
✅ Verifique pino 30 do receptor IR
✅ Teste com Serial Monitor para ver códigos
✅ Troque receptor se necessário
```

#### 5. Matriz LED não acende
```
Problema: Display não mostra nada

Soluções:
✅ Verifique pinos DIN (22), CLK (24), CS (26)
✅ Confirme alimentação 5V estável
✅ Teste com código de exemplo do LedControl
✅ Verifique orientação do módulo MAX7219
```

---

## 🤝 Contribuindo

Contribuições são sempre bem-vindas! Siga os passos:

### Como Contribuir

1. **Fork** o projeto
2. **Clone** seu fork
   ```bash
   git clone https://github.com/seu-usuario/OTTO_v1_v2.git
   ```
3. Crie uma **branch** para sua feature
   ```bash
   git checkout -b feature/MinhaFeature
   ```
4. **Commit** suas mudanças
   ```bash
   git commit -m "Adiciona: Minha nova feature"
   ```
5. **Push** para a branch
   ```bash
   git push origin feature/MinhaFeature
   ```
6. Abra um **Pull Request**

### Diretrizes

- 📝 Comente seu código adequadamente
- ✅ Teste antes de enviar
- 📚 Atualize documentação se necessário
- 🎯 Mantenha código limpo e organizado
- 🐛 Reporte bugs com detalhes

---

## 👥 Autores

### 💻 Desenvolvimento de Software

<table>
  <tr>
    <td align="center">
      <a href="https://github.com/defaultdayanni">
        Foto Dayanni<br>
        <sub>
          <b>Dayanni</b><br>
          <small>Programação & Eletrônica</small>
        </sub>
         <td align="center">
      <a href="https://github.com/DebbieMatt" title="Colaboradora">
        Foto da Débora<br>
        <sub>
          <b>Débora Mateus</b><br>
          <small>Programação & Eletrônica</small>
         </sub>
</table>

### 🎨 Modelagem 3D

<table>
  <tr>
    <td align="center">
      <a href="https://github.com/gabereboucas">
        Foto do Gabriel Rebouças<br>
        <sub>
          <b>Gabriel Rebouças</b><br>
          <small>Modelagem & Impressão 3D</small>
        </sub>
      </a>
    </td>
  </tr>
</table>

---

## 📚 Referências

### Documentação Oficial

- [Arduino - Referência Oficial](https://www.arduino.cc/reference/en/)
- [Arduino IDE - Download](https://www.arduino.cc/en/software)
- [Arduino - Versões Anteriores](https://www.arduino.cc/en/software/OldSoftwareReleases)

### Bibliotecas

- [DFPlayer Mini - DFRobot](https://github.com/DFRobot/DFRobotDFPlayerMini)
- [MFRC522 - RFID Library](https://github.com/miguelbalboa/rfid)
- [IRremote - Arduino](https://github.com/Arduino-IRremote/Arduino-IRremote)
- [Keypad - Arduino Playground](https://playground.arduino.cc/Code/Keypad/)
- [LedControl - Wayoda](https://github.com/wayoda/LedControl)

### Ferramentas

- [Visual Studio C++](https://visualstudio.microsoft.com/pt-br/)
- [Java Runtime Environment](https://www.java.com/pt-BR/download/)
- [Autodesk Fusion 360](https://www.autodesk.com/products/fusion-360/)
- [Ultimaker Cura](https://ultimaker.com/software/ultimaker-cura)

### Projetos Relacionados

- [Otto DIY - Projeto Original](https://www.ottodiy.com/)
- [Arduino Servo Library](https://www.arduino.cc/reference/en/libraries/servo/)
- [SPI Communication](https://www.arduino.cc/en/reference/SPI)

---

## 📄 Licença

Este projeto está sob a licença MIT. Veja o arquivo [LICENSE](LICENSE) para mais detalhes.

```
MIT License

Copyright (c) 2024 Otto UFMT

Permission is hereby granted, free of charge, to any person obtaining a copy
of this software and associated documentation files (the "Software"), to deal
in the Software without restriction, including without limitation the rights
to use, copy, modify, merge, publish, distribute, sublicense, and/or sell
copies of the Software...
```

---

### 💙 Se este projeto foi útil, considere dar uma ⭐!

**[⬆ Voltar ao topo](#-robô-otto-10---repositório-oficial)**

---

**Desenvolvido com ❤️ pela equipe Otto UFMT**



</div>

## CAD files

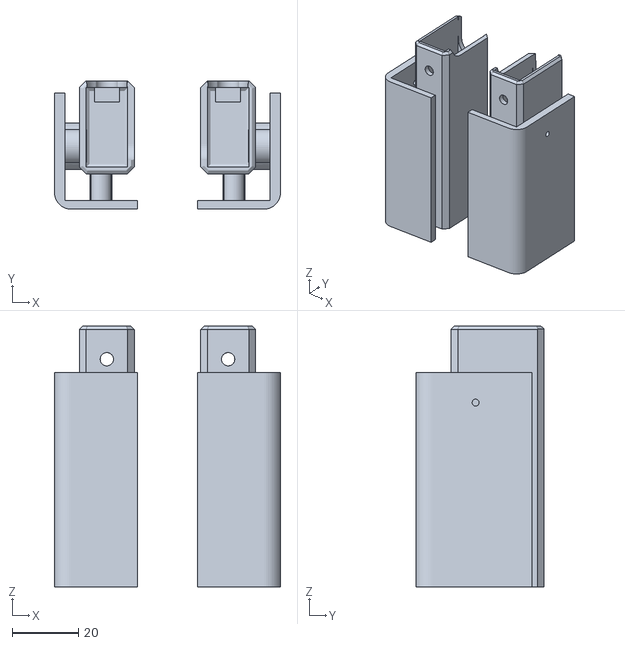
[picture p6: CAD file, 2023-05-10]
Modelagem_3d/amarelo/bracos_amarelo.stl
68.0 x 38.6 x 78.6

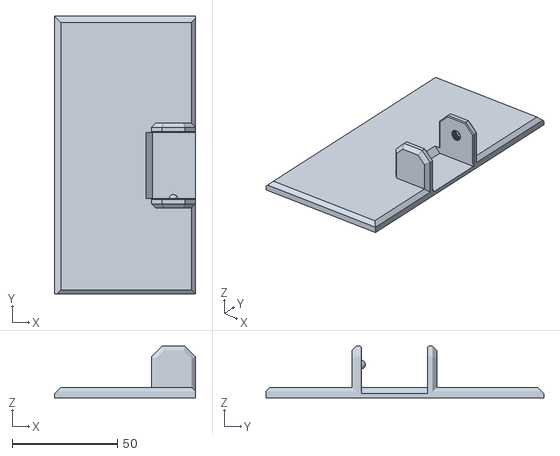
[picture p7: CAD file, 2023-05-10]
Modelagem_3d/preto/pe_esq_preto.stl
67.0 x 132.0 x 24.5

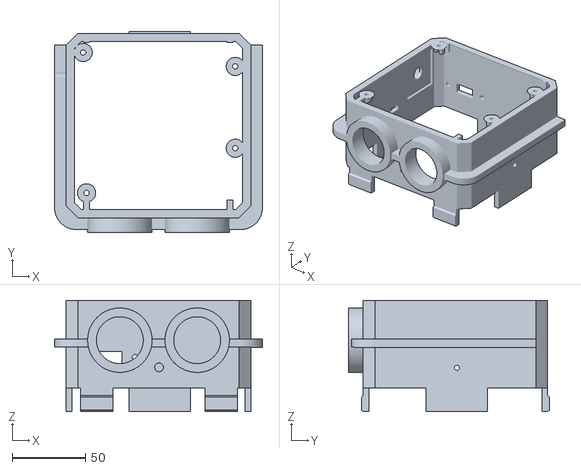
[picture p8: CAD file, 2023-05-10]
Modelagem_3d/amarelo/cut_cabeça.stl
142.0 x 137.2 x 76.0

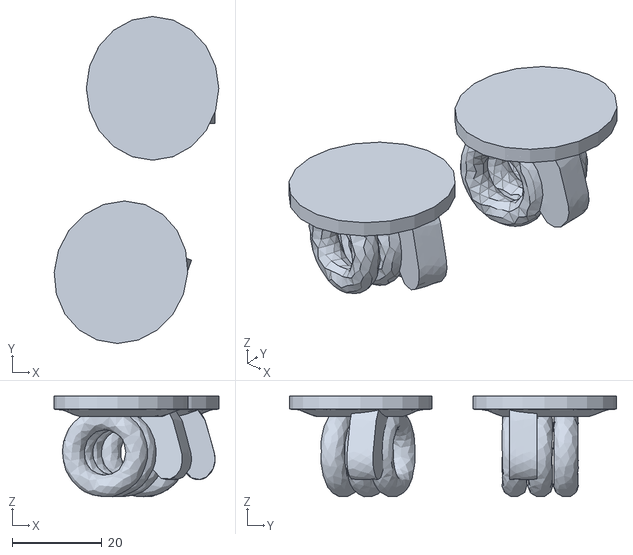
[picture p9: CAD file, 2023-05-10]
Modelagem_3d/preto/maos_preto.stl
36.7 x 72.8 x 22.4

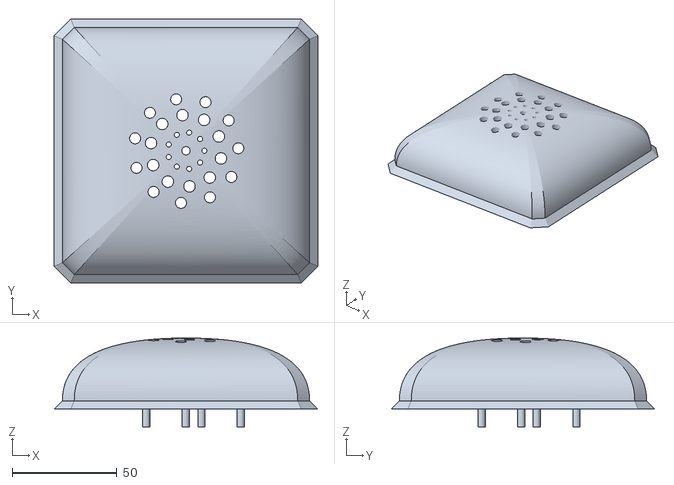
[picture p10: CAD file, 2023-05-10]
Modelagem_3d/amarelo/cut2_cabeça.stl
126.0 x 126.0 x 42.5

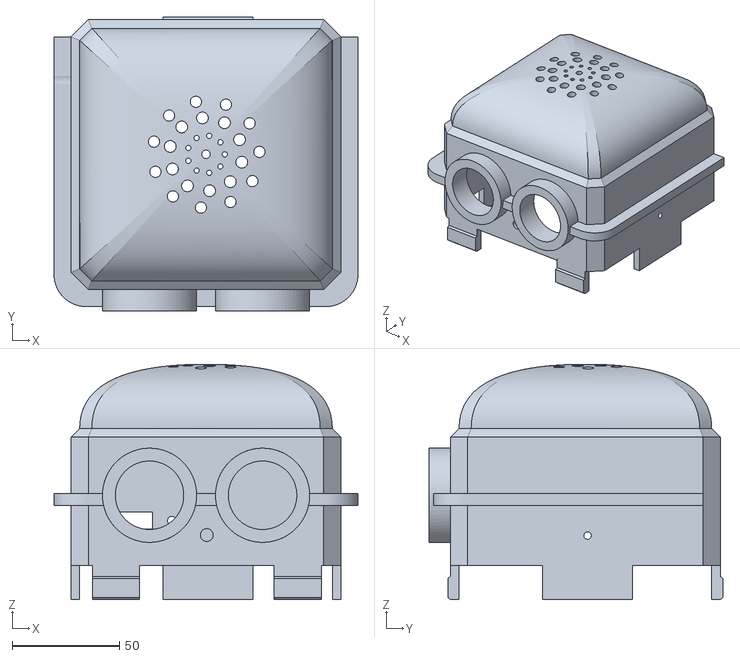
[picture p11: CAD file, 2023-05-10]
Modelagem_3d/amarelo/(demo) cabeca_amarelo.stl
142.0 x 137.2 x 110.0

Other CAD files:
Modelagem_3d/preto/pe_direito_preto.stl
old_versions/Otto 1.0 - stl/preto/pe_direito_preto.stl

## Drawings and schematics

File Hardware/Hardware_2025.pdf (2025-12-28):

# Bateria

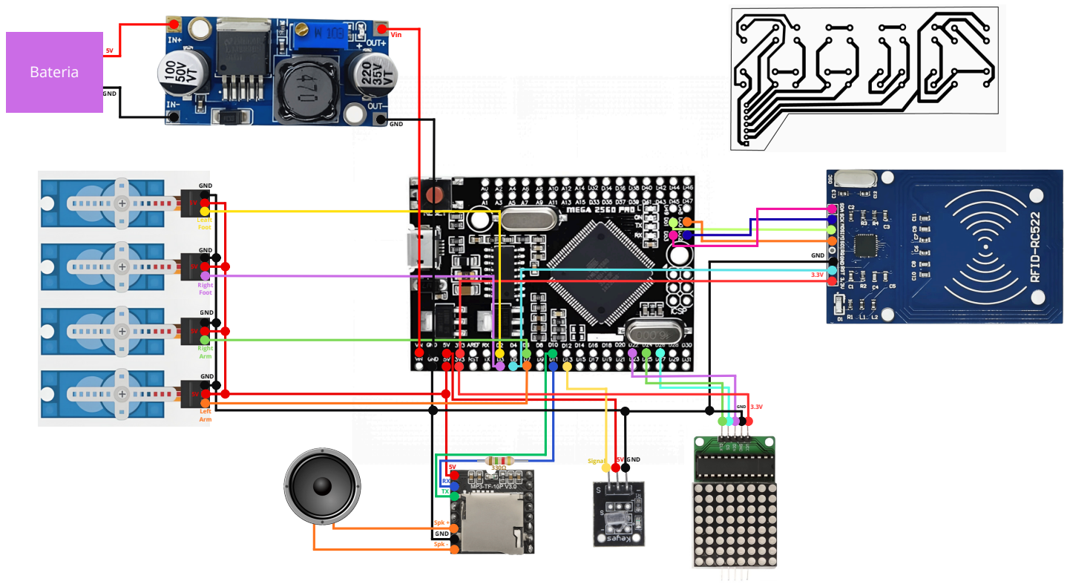
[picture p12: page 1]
RXTX Spk + Spk - GND; GND; GND GND GND GND GND; GND Vin Leaft; Foot; Right Foot; Right Arm; Left Arm; 3.3V Signal 5V GND

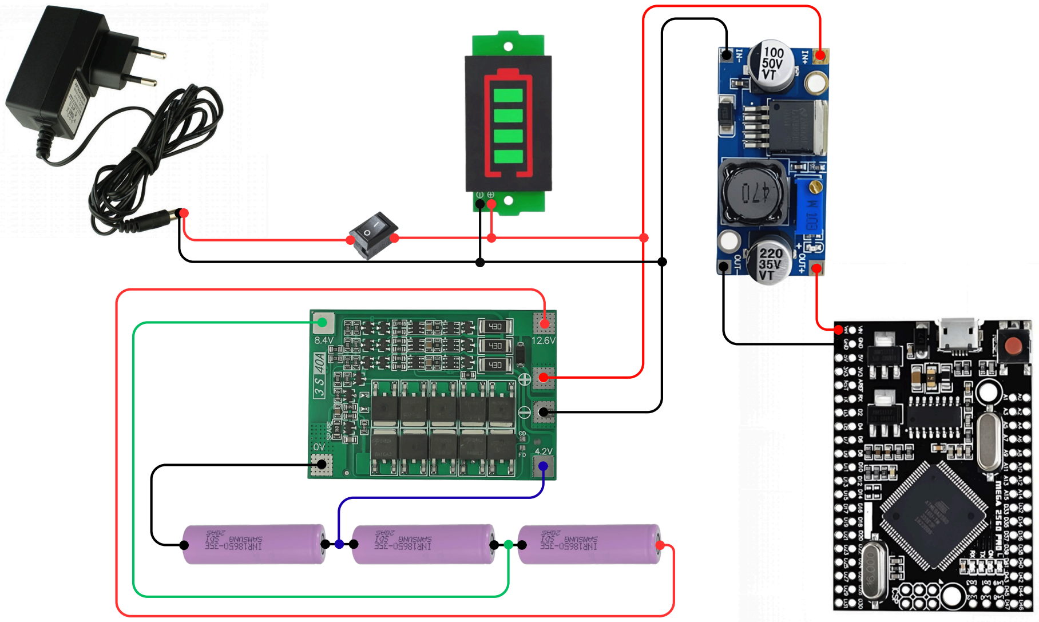
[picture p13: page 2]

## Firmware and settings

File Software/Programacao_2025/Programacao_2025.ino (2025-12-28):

// OTTO Robot - Código Refatorado e Otimizado
// Versão Melhorada - Dezembro 2025

#include <DFRobotDFPlayerMini.h>
#include <SPI.h>
#include <SoftwareSerial.h>
#include <MFRC522.h>
#include <Keypad.h>
#include <IRremote.h>
#include <avr/wdt.h>
#include <LedControl.h>
#include <Servo.h>

// ============================================
// DEFINIÇÕES DE PINOS
// ============================================
#define PIN_LEFT_FOOT    2
#define PIN_RIGHT_FOOT   3
#define PIN_LEFT_ARM     6
#define PIN_RIGHT_ARM    7
#define PIN_RFID_RST     5
#define PIN_RFID_SS      53
#define PIN_IR_RECV      13
#define PIN_LED_DIN      22
#define PIN_LED_CLK      24
#define PIN_LED_CS       26

// ============================================
// DEFINIÇÕES DE ÁUDIO (DFPLAYER)
// ============================================
enum AudioFiles {
  AUDIO_LIGA = 1,
  AUDIO_DESLIGA = 2,
  AUDIO_ACERTOU = 3,
  AUDIO_ERROU = 4,
  AUDIO_DANCA = 5,
  AUDIO_TRISTE = 84,
  AUDIO_FELIZ = 85,
  AUDIO_VERGONHA = 86,
  AUDIO_MEDO = 87,
  AUDIO_RAIVA = 89,
  AUDIO_BARULHO = 90,
  AUDIO_ENJOADO = 91,
  AUDIO_TE_AMO = 95,
  AUDIO_TECLADO_0 = 97,
  AUDIO_TECLADO_1 = 98,
  AUDIO_PARABENS = 107,
  AUDIO_CANSADA = 108
};

// ============================================
// DEFINIÇÕES DE CONTROLE IR
// ============================================
#define IR_POWER    0xBA45FF00
#define IR_BTN_1    0xF30CFF00
#define IR_BTN_3    0xA15EFF00
#define IR_BTN_5    0xE31CFF00
#define IR_BTN_VERDE 0xB847FF00

// ============================================
// OBJETOS GLOBAIS
// ============================================
Servo servoLeftFoot, servoRightFoot;
Servo servoLeftArm, servoRightArm;

SoftwareSerial dfPlayerSerial(10, 11);
DFRobotDFPlayerMini dfPlayer;
MFRC522 rfid(PIN_RFID_SS, PIN_RFID_RST);
MFRC522::MIFARE_Key rfidKey;
IRrecv irReceiver(PIN_IR_RECV);
LedControl ledMatrix = LedControl(PIN_LED_DIN, PIN_LED_CLK, PIN_LED_CS, 1);

// ============================================
// TECLADO MATRICIAL
// ============================================
const byte KEYBOARD_ROWS = 2;
const byte KEYBOARD_COLS = 5;
const byte rowPins[KEYBOARD_ROWS] = {40, 38};
const byte colPins[KEYBOARD_COLS] = {42, 44, 46, 48, 49};
const char keys[KEYBOARD_ROWS][KEYBOARD_COLS] = {
  {'0', '1', '2', '3', '4'},
  {'5', '6', '7', '8', '9'}
};
Keypad keyboard = Keypad(makeKeymap(keys), rowPins, colPins, KEYBOARD_ROWS, KEYBOARD_COLS);

// ============================================
// VARIÁVEIS DE ESTADO
// ============================================
struct RobotState {
  bool isOn;
  bool keyboardEnabled;
  int currentPosition;
} robot = {false, false, 0};

// ============================================
// EXPRESSÕES FACIAIS (LED MATRIX)
// ============================================
const byte FACE_SMILE[] = {
  B01111000, B01101100, B01100110, B01100110,
  B01100110, B01100110, B01101100, B01111000
};

const byte FACE_SAD[] = {
  B00000110, B00011000, B00110000, B00100000,
  B00100000, B00110000, B00011000, B00000110
};

const byte FACE_SHY[] = {
  B00010000, B00011000, B00001000, B00000100,
  B00000100, B00001000, B00011000, B00010000
};

const byte FACE_SURPRISED[] = {
  B00111100, B01111110, B11111111, B11111111,
  B11111111, B11111111, B01111110, B00111100
};

const byte FACE_TIRED[] = {
  B00001000, B00010000, B00010000, B00010000,
  B00010000, B00010000, B00010000, B00010000
};

const byte FACE_NEUTRAL[] = {
  B00010000, B00010000, B00010000, B00010000,
  B00010000, B00010000, B00010000, B00010000
};

const byte FACE_EMPTY[] = {
  B00000000, B00000000, B00000000, B00000000,
  B00000000, B00000000, B00000000, B00000000
};

const byte FACE_HEART[] = {
  B01110000, B11111000, B01111100, B00111110,
  B00111110, B01111100, B11111000, B01110000
};

const byte FACE_MOUTH_OPEN1[] = {
  B00010000, B00101000, B00101000, B00101000,
  B00101000, B00101000, B00101000, B00010000
};

const byte FACE_MOUTH_OPEN2[] = {
  B00010000, B00101000, B01000100, B01000100,
  B01000100, B01000100, B00101000, B00010000
};

const byte FACE_SCARED[] = {
  B00010000, B00001000, B00010000, B00001000,
  B00010000, B00001000, B00010000, B00001000
};

const byte FACE_ANGRY[] = {
  B00011110, B00101001, B01001001, B01001010,
  B01001010, B01001001, B00101001, B00011110
};

const byte FACE_NOISE[] = {
  B00111100, B01111100, B11111100, B11111100,
  B11111100, B11111100, B01111100, B00111100
};

const byte FACE_SICK[] = {
  B00011000, B00011000, B00011000, B10011001,
  B10011001, B11111111, B11111111, B00000000
};

// ============================================
// FUNÇÕES DE CONTROLE DE SERVOS
// ============================================

/**
 * attachFeet()
 * Ativa os servos das pernas do robô
 * 
 * Descrição: Associa os pinos físicos aos objetos Servo das pernas,
 * permitindo que elas sejam controladas. Deve ser chamada antes de
 * qualquer movimento de pernas.
 */
void attachFeet() {
  servoLeftFoot.attach(PIN_LEFT_FOOT);   // Ativa servo da perna esquerda no pino 2
  servoRightFoot.attach(PIN_RIGHT_FOOT); // Ativa servo da perna direita no pino 3
}

/**
 * attachArms()
 * Ativa os servos dos braços do robô
 * 
 * Descrição: Associa os pinos físicos aos objetos Servo dos braços,
 * permitindo que eles sejam controlados. Deve ser chamada antes de
 * qualquer movimento de braços.
 */
void attachArms() {
  servoLeftArm.attach(PIN_LEFT_ARM);   // Ativa servo do braço esquerdo no pino 6
  servoRightArm.attach(PIN_RIGHT_ARM); // Ativa servo do braço direito no pino 7
}

/**
 * attachRightArm()
 * Ativa apenas o servo do braço direito
 * 
 * Descrição: Função especial que ativa temporariamente o braço esquerdo
 * e depois desativa, mantendo apenas o braço direito ativo. Útil para
 * movimentos que usam apenas um braço (como acenar).
 */
void attachRightArm() {
  servoLeftArm.attach(PIN_LEFT_ARM);  // Ativa temporariamente braço esquerdo
  servoLeftArm.detach();              // Desativa braço esquerdo imediatamente
  servoRightArm.attach(PIN_RIGHT_ARM); // Mantém apenas braço direito ativo
}

/**
 * detachAll()
 * Desativa todos os servos do robô
 * 
 * Descrição: Desassocia todos os servos de seus pinos, liberando-os
 * e reduzindo consumo de energia. Os servos param de consumir corrente
 * e ficam "soltos". Deve ser chamada após completar movimentos.
 */
void detachAll() {
  servoLeftFoot.detach();  // Desativa servo da perna esquerda
  servoRightFoot.detach(); // Desativa servo da perna direita
  servoLeftArm.detach();   // Desativa servo do braço esquerdo
  servoRightArm.detach();  // Desativa servo do braço direito
}

// ============================================
// FUNÇÕES DE DISPLAY (LED MATRIX)
// ============================================

/**
 * showFace(faceData)
 * Exibe uma expressão facial na matriz de LEDs
 * 
 * @param faceData - Array de 8 bytes representando a face (cada byte é uma linha)
 * 
 * Descrição: Recebe um padrão de face (8x8 pixels) e envia linha por linha
 * para a matriz de LEDs. Cada byte representa uma linha horizontal de 8 LEDs,
 * onde 1 = LED aceso e 0 = LED apagado.
 * 
 * Exemplo: FACE_SMILE mostra um sorriso na matriz
 */
void showFace(const byte* faceData) {
  for (int i = 0; i < 8; i++) {              // Loop pelas 8 linhas da matriz
    ledMatrix.setRow(0, i, faceData[i]);     // Define cada linha com o padrão correspondente
  }
}

/**
 * animateSleeping()
 * Animação de "dormindo" com transições suaves
 * 
 * Descrição: Cria uma animação de sono em 5 frames, simulando o robô
 * piscando e ficando sonolento. Útil para demonstrar cansaço ou inatividade.
 * A animação dura aproximadamente 3.5 segundos no total.
 * 
 * Sequência:
 * 1. Face cansada (700ms)
 * 2. Face neutra (700ms) 
 * 3. Face surpresa - "Z" pequeno (700ms)
 * 4. Face neutra (700ms)
 * 5. Face cansada final (1000ms)
 */
void animateSleeping() {
  const byte* sleepFrames[] = {FACE_TIRED, FACE_NEUTRAL, FACE_SURPRISED, FACE_NEUTRAL, FACE_TIRED};
  const int frameDelays[] = {700, 700, 700, 700, 1000};
  
  for (int i = 0; i < 5; i++) {              // Percorre os 5 frames da animação
    showFace(sleepFrames[i]);                // Mostra o frame atual
    delay(frameDelays[i]);                   // Aguarda tempo específico do frame
  }
}

/**
 * animateTalking()
 * Animação de "falando" com movimento de boca
 * 
 * Descrição: Simula o robô falando abrindo e fechando a boca em 3 etapas.
 * Deve ser chamada enquanto áudio está tocando para sincronizar movimento
 * visual com som. Total de 1.7 segundos de animação.
 * 
 * Sequência:
 * 1. Boca pouco aberta (500ms)
 * 2. Boca muito aberta (500ms)
 * 3. Boca pouco aberta novamente (700ms)
 */
void animateTalking() {
  showFace(FACE_MOUTH_OPEN1);                // Boca levemente aberta
  delay(500);
  showFace(FACE_MOUTH_OPEN2);                // Boca bem aberta
  delay(500);
  showFace(FACE_MOUTH_OPEN1);                // Boca levemente aberta novamente
  delay(700);
}

// ============================================
// FUNÇÕES DE MOVIMENTO - POSIÇÕES
// ============================================

/**
 * moveToInitialPosition()
 * Move os braços para a posição de repouso/inicial
 * 
 * Descrição: Retorna ambos os braços para uma posição neutra e confortável
 * após executar movimentos. Braço direito vai para ~84° e esquerdo para ~76°.
 * Esta posição é considerada a "pose padrão" do robô quando parado.
 * 
 * Uso: Chamar após completar qualquer sequência de movimento dos braços
 */
void moveToInitialPosition() {
  attachArms();                              // Ativa os servos dos braços
  delay(10);                                 // Aguarda estabilização
  
  for (int pos = 120; pos >= 84; pos -= 2) { // Move braços gradualmente (de 120° até 84°)
    servoRightArm.write(pos);                // Posiciona braço direito
    servoLeftArm.write(160 - pos);           // Posiciona braço esquerdo (espelhado)
    delay(12);                               // Delay entre passos para movimento suave
  }
  
  detachAll();                               // Desativa servos para economizar energia
}

/**
 * smoothServoMove(servo, startPos, endPos, stepSize, delayMs)
 * Move um servo suavemente de uma posição para outra
 * 
 * @param servo - Referência ao objeto Servo a ser movido
 * @param startPos - Posição inicial em graus (0-180)
 * @param endPos - Posição final em graus (0-180)
 * @param stepSize - Tamanho do passo em graus (quanto maior, mais rápido)
 * @param delayMs - Delay em milissegundos entre cada passo
 * 
 * Descrição: Função genérica que move qualquer servo de forma suave,
 * detectando automaticamente se deve incrementar ou decrementar.
 * Elimina código duplicado e torna movimentos mais previsíveis.
 * 
 * Exemplo: smoothServoMove(servoRightArm, 0, 180, 2, 10)
 *          Move braço direito de 0° a 180° em passos de 2° com 10ms entre passos
 */
void smoothServoMove(Servo &servo, int startPos, int endPos, int stepSize, int delayMs) {
  if (startPos < endPos) {                   // Se posição inicial é menor que final
    for (int pos = startPos; pos <= endPos; pos += stepSize) {  // Incrementa posição
      servo.write(pos);                      // Move servo para posição atual
      delay(delayMs);                        // Aguarda antes do próximo passo
    }
  } else {                                   // Se posição inicial é maior que final
    for (int pos = startPos; pos >= endPos; pos -= stepSize) {  // Decrementa posição
      servo.write(pos);                      // Move servo para posição atual
      delay(delayMs);                        // Aguarda antes do próximo passo
    }
  }
}

// ============================================
// MOVIMENTOS - BRAÇOS
// ============================================

/**
 * waveHand()
 * Faz o robô acenar com o braço direito
 * 
 * Descrição: Movimento de cumprimento/despedida usando principalmente o braço direito.
 * O braço faz uma série de movimentos de vai-e-vem simulando um aceno amigável.
 * Usado quando o robô liga/desliga ou cumprimenta alguém.
 * 
 * Sequência do movimento:
 * 1. Braço sobe para posição inicial (100° → 50°)
 * 2. Acena 3 vezes (0° ↔ 150° com velocidades variadas)
 * 3. Ambos os braços voltam juntos à posição inicial
 * 
 * Duração total: ~3-4 segundos
 */
void waveHand() {
  attachRightArm();                          // Ativa apenas braço direito
  delay(50);                                 // Aguarda estabilização do servo
  
  // Sequência de posições do braço durante o aceno
  // Cada posição representa um ponto-chave do movimento
  int waveSequence[] = {100, 50, 0, 150, 0, 150, 0, 150, 50};
  int waveDelays[] = {13, 12, 12, 12, 10, 12, 12}; // Velocidades variadas para naturalidade
  
  // Executa sequência de acenos
  for (int i = 0; i < 7; i++) {
    smoothServoMove(servoRightArm, waveSequence[i], waveSequence[i+1], 2, waveDelays[i]);
  }
  
  // Retorna à posição inicial com movimento sincronizado
  smoothServoMove(servoLeftArm, 150, 50, 2, 12);
  
  detachAll();                               // Desativa servos
  moveToInitialPosition();                   // Retorna à pose padrão
}

/**
 * celebrateSuccess()
 * Movimento de comemoração - braços para cima e para baixo
 * 
 * Descrição: Animação de alegria/vitória onde ambos os braços sobem e descem
 * repetidamente de forma sincronizada e espelhada. Usado quando o robô
 * acerta algo, está feliz ou parabeniza alguém.
 * 
 * Movimento:
 * - 4 ciclos completos de braços subindo e descendo
 * - Braços se movem de forma espelhada (simétrica)
 * - Velocidade aumenta gradualmente (primeiros ciclos mais lentos)
 * - Braço direito: 150° → 0° → 150°
 * - Braço esquerdo: 30° → 180° → 30° (espelhado)
 * 
 * Duração total: ~5-6 segundos
 */
void celebrateSuccess() {
  attachArms();                              // Ativa ambos os braços
  delay(50);
  
  // 4 ciclos de comemoração com velocidades variadas
  for (int cycle = 0; cycle < 4; cycle++) {
    
    // Braços vão para baixo (posição 0° / 180°)
    for (int pos = 150; pos >= 0; pos -= 2) {
      servoRightArm.write(pos);              // Braço direito desce
      servoLeftArm.write(180 - pos);         // Braço esquerdo sobe (espelhado)
      delay(cycle == 0 ? 12 : 8);            // Primeiro ciclo mais lento
    }
    
    // Braços voltam para cima (posição 150° / 30°)
    for (int pos = 0; pos <= 150; pos += 2) {
      servoRightArm.write(pos);              // Braço direito sobe
      servoLeftArm.write(180 - pos);         // Braço esquerdo desce (espelhado)
      delay(cycle < 2 ? 12 : 8);             // Primeiros 2 ciclos mais lentos
    }
  }
  
  // Retorna suavemente à posição de repouso
  smoothServoMove(servoRightArm, 150, 50, 2, 12);
  smoothServoMove(servoLeftArm, 30, 50, 2, 12);
  
  detachAll();
  moveToInitialPosition();
}

/**
 * showSadness()
 * Movimento de tristeza - braços caem desanimados
 * 
 * Descrição: Simula tristeza/decepção fazendo os braços caírem lentamente
 * para baixo e ficarem pendurados por 2 segundos antes de voltar.
 * Usado quando o robô erra algo ou mostra emoção de tristeza.
 * 
 * Movimento:
 * 1. Braços caem gradualmente até posição 0° (totalmente para baixo)
 * 2. Pausa de 2 segundos na posição caída (efeito dramático)
 * 3. Braços voltam lentamente para posição inicial
 * 
 * Duração total: ~5 segundos (incluindo pausa)
 */
void showSadness() {
  attachArms();
  delay(50);
  
  // Braços caem lentamente (movimento de desânimo)
  for (int pos = 150; pos >= 0; pos -= 2) {
    servoLeftArm.write(pos);                 // Braço esquerdo cai
    servoRightArm.write(180 - pos);          // Braço direito cai (espelhado)
    delay(12);                               // Movimento lento para dramaticidade
  }
  
  delay(2000);                               // Pausa com braços caídos (2 segundos)
  
  // Retorna à posição inicial de forma gradual
  for (int pos = 150; pos >= 50; pos -= 2) {
    servoRightArm.write(pos);
    servoLeftArm.write(160 - pos);
    delay(12);
  }
  
  detachAll();
  moveToInitialPosition();
}
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
void loop() {
  // ==========================================
  // WATCHDOG RESET - PREVINE TRAVAMENTOS
  // ==========================================
  wdt_reset();                               // "Alimenta" watchdog dizendo "estou vivo!"
                                             // Se não chamar isso, Arduino reseta após timeout
  
  // ==========================================
  // PROCESSA CONTROLE REMOTO INFRAVERMELHO
  // ==========================================
  if (IrReceiver.decode()) {                 // Verifica se recebeu sinal IR
    unsigned long code = IrReceiver.decodedIRData.decodedRawData;  // Pega código recebido
    Serial.print("IR Code: ");               // Log para debug
    Serial.println(code, HEX);               // Mostra código em hexadecimal
    
    detachAll();                             // Desativa todos servos antes de processar
    
    // === SWITCH PARA PROCESSAR CADA BOTÃO DO CONTROLE ===
    switch (code) {
      
      // ------------------------------------------
      // BOTÃO POWER - LIGA/DESLIGA ROBÔ
      // ------------------------------------------
      case IR_POWER:
        Serial.println("Power button");
        
        if (!robot.isOn) {                   // Se robô está DESLIGADO
          Serial.println("Ligando OTTO");
          dfPlayer.play(AUDIO_LIGA);         // Toca som de inicialização
          showFace(FACE_HEART);              // Mostra coração (carinho ao ligar)
          robot.isOn = true;                 // Marca robô como ligado
          waveHand();                        // Acena cumprimentando
          delay(1000);                       // Mantém coração por 1 segundo
          showFace(FACE_NEUTRAL);            // Volta à face neutra
          
        } else {                             // Se robô está LIGADO
          Serial.println("Desligando OTTO");
          dfPlayer.play(AUDIO_DESLIGA);      // Toca som de despedida
          waveHand();                        // Acena se despedindo
          delay(1500);                       // Aguarda término do aceno
          showFace(FACE_EMPTY);              // Apaga face (display vazio)
          shutdownRobot();                   // Executa desligamento completo
        }
        break;
      
      // ------------------------------------------
      // BOTÃO 1 - RESPOSTA POSITIVA (ACERTOU)
      // ------------------------------------------
      case IR_BTN_1:
        if (robot.isOn) {                    // Só funciona se robô estiver ligado
          dfPlayer.play(AUDIO_ACERTOU);      // Toca som de acerto/aplausos
          showFace(FACE_SMILE);              // Mostra sorriso
          celebrateSuccess();                // Braços comemoram
          Serial.println("Acertou - Aplausos");
          delay(1000);
          showFace(FACE_NEUTRAL);
        }
        break;
      
      // ------------------------------------------
      // BOTÃO 3 - RESPOSTA NEGATIVA (ERROU)
      // ------------------------------------------
      case IR_BTN_3:
        if (robot.isOn) {                    // Só funciona se robô estiver ligado
          dfPlayer.play(AUDIO_ERROU);        // Toca som de erro
          showFace(FACE_SAD);                // Mostra face triste
          showSadness();                     // Braços caem desanimados
          Serial.println("Errou");
          delay(1000);
          showFace(FACE_NEUTRAL);
        }
        break;
      
      // ------------------------------------------
      // BOTÃO 5 - MODO DANÇA
      // ------------------------------------------
      case IR_BTN_5:
        if (robot.isOn) {                    // Só funciona se robô estiver ligado
          dfPlayer.play(AUDIO_DANCA);        // Toca música de dança
          performDance();                    // Executa coreografia completa
          Serial.println("Dança");
        }
        break;
      
      // ------------------------------------------
      // BOTÃO VERDE - LIGA/DESLIGA TECLADO
      // ------------------------------------------
      case IR_BTN_VERDE:
        robot.keyboardEnabled = !robot.keyboardEnabled;  // Inverte estado (toggle)
        Serial.print("Teclado: ");
        Serial.println(robot.keyboardEnabled ? "LIGADO" : "DESLIGADO");
        break;
    }
    
    irReceiver.resume();                     // Prepara para receber próximo sinal IR
  }
  
  // ==========================================
  // PROCESSA TECLADO MATRICIAL
  // ==========================================
  char key = keyboard.getKey();              // Lê tecla pressionada (retorna 0 se nenhuma)
  
  if (key && robot.keyboardEnabled) {        // Se há tecla E teclado está habilitado
    Serial.print("Tecla: ");
    Serial.println(key);
    
    // Converte caractere da tecla em número de arquivo de áudio
    // '0' → 97, '1' → 98, '2' → 99, ... '9' → 106
    int audioFile = AUDIO_TECLADO_0 + (key - '0');
    
    // Valida se número está no range correto (97 a 106)
    if (audioFile >= AUDIO_TECLADO_0 && audioFile <= AUDIO_TECLADO_1 + 9) {
      dfPlayer.play(audioFile);              // Toca áudio correspondente à tecla
    }
  }
  
  // ==========================================
  // PROCESSA CARTÕES RFID
  // ==========================================
  // Verifica se robô está ligado E se há cartão novo presente
  if (robot.isOn && rfid.PICC_IsNewCardPresent()) {
    processRFIDCard();                       // Lê cartão e executa comando
  }
  
  // ==========================================
  // DELAY ENTRE CICLOS
  // ==========================================
  delay(500);                                // Aguarda 500ms antes do próximo ciclo
                                             // Evita leituras múltiplas e dá tempo para processar
  
  // Loop reinicia automaticamente - volta ao início do loop()
}

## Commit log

2023-07-26 Add files via upload
    Conexão das baterias de lítio 18650 3,7V na placa BMS (carregamento e distribuição de tensão)
    Placa BMS
    - Proteção contra sobrecarga e descarga excessiva
    - Proteção contra sobrecorrente
    - Proteção contra excesso de temperatura
    - Circuito de detecção de tensão de alta precisão
    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
2024-08-30 Rename WhatsApp Image 2024-08-29 at 16.48.52.jpeg to Reprodutor de MP3.jpeg
2024-08-30 Rename WhatsApp Image 2024-08-29 at 16.51.09.jpeg to Esquemático Circuito.jpeg
2025-12-28 Refatora projeto: atualiza código, esquemas e cria pasta legacy
    - Atualiza código com as definições de entradas/pinos do hardware atual.
    - Atualiza versões das bibliotecas necessárias.
    - Substitui imagens dos esquemas eletrônicos (qualidade melhorada e componentes corrigidos).
    - Move arquivos da versão anterior para a nova pasta 'legacy' para manter histórico.
    - Atualiza README.md
    [(demo) cabeca_amarelo.stl, bracos_amarelo.stl, cut2_cabeça.stl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]
2025-12-28 Remove duplicate 'Desenvolvimento de Software' header
    Removed duplicate section header for software development.

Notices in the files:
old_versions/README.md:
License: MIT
